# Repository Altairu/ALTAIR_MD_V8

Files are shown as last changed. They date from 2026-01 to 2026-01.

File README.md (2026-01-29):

# ALTAIR_MD_V8
**High-Power Isolated Motor Driver Board**

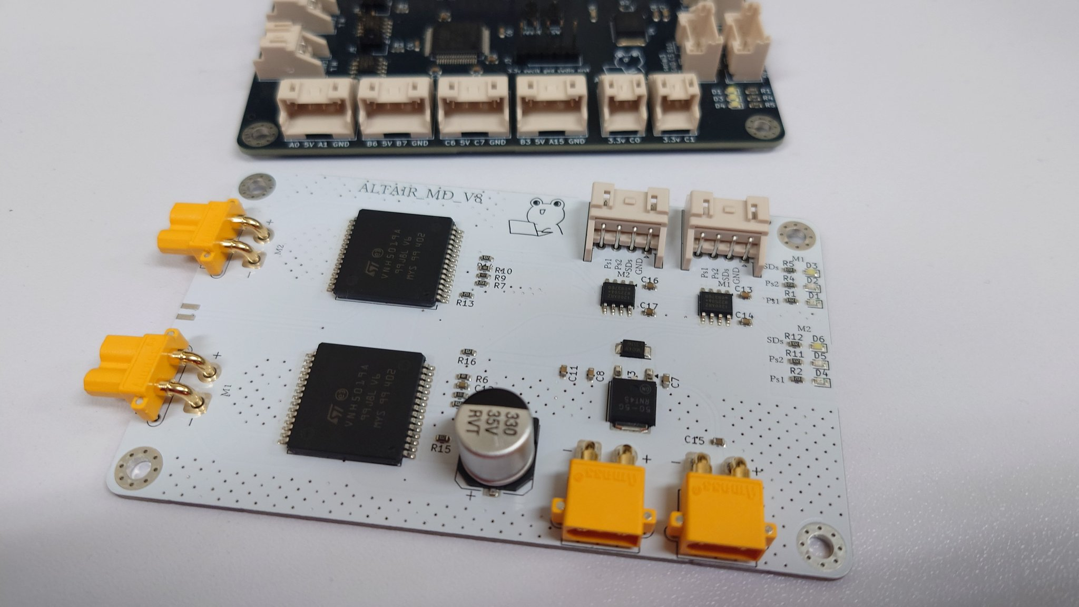
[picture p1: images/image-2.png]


<blockquote class="twitter-tweet"><p lang="ja" dir="ltr">NEWもたどら <a href="https://t.co/xIfIAs8RRS">pic.twitter.com/xIfIAs8RRS</a></p>&mdash; -Altair- (@Flying___eagle) <a href="https://twitter.com/Flying___eagle/status/2016806401205797079?ref_src=twsrc%5Etfw">January 29, 2026</a></blockquote> 

## 概要 (Overview)
**ALTAIR_MD_V8** は、STMicroelectronics製の車載用高出力フルブリッジドライバー **VNH5019A-E** を搭載したDCモータードライバーモジュールです。

制御信号ラインにデジタルアイソレータ (**ADuM121N**) を採用することで、モーター駆動系（24V系）とマイコン制御系（3.3V/5V系）のGNDを完全に分離（絶縁）しています。

## 特徴 (Features)
*   **高出力駆動**: 連続12A / 最大30A の大電流駆動が可能（VNH5019A-E仕様に基づく）。
*   **完全絶縁設計**: Analog Devices製 デジタルアイソレータ ADuM121N を採用し、ロジック側とパワー側のGNDを分離。
*   **広範囲なロジック電圧**: 1.8V ～ 5V のロジック入力に対応（マイコンを選ばない設計）。
*   **保護機能**:
    *   過電圧・低電圧シャットダウン
    *   過熱保護 (Thermal Shutdown)
    *   電流センシング機能 (Current Sense Output)

## 仕様 (Specifications)

| 項目 | 仕様 | 備考 |
| :--- | :--- | :--- |
| **メインドライバー** | STMicroelectronics VNH5019A-E | AEC-Q100準拠 (車載グレード) |
| **絶縁素子** | Analog Devices ADuM121N | 2ch デジタルアイソレータ (計2個使用) |
| **入力電源電圧** | DC 5.5V ～ 24V | パワー側電源 (VCC/VBAT) |
| **ロジック入力電圧** | DC 1.8V ～ 5.5V | マイコン側I/O電圧 |
| **最大出力電流** | 連続 12A / ピーク 30A | 放熱条件に依存 |
| **電流センシング** | アナログ電圧出力 | 1.5kΩ抵抗接続時 (約0.14V/A) |

## 回路図 (Schematic)

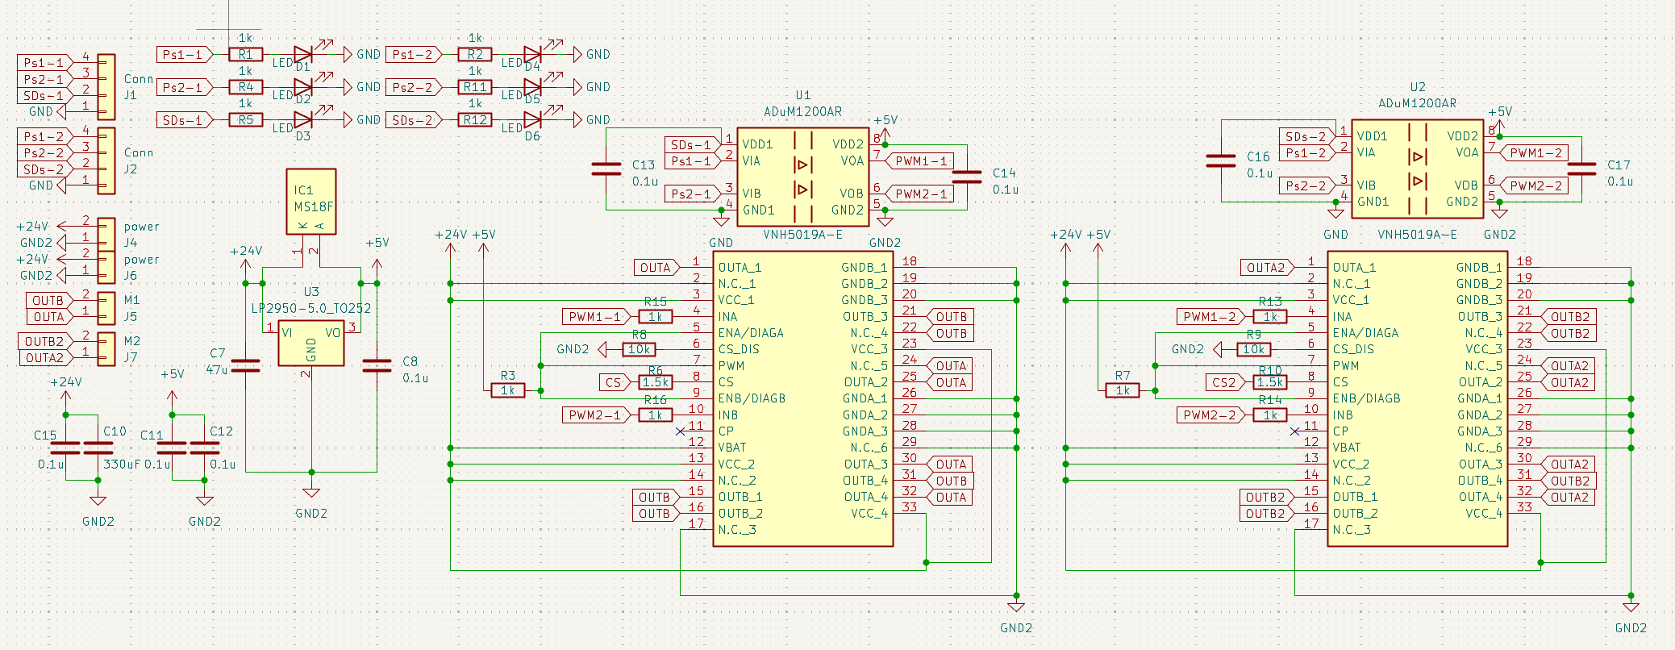
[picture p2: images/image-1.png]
Circuit Diagram


### 主な構成
*   **絶縁回路**: マイコンからの制御信号（PWM1, PWM2, ENABLE）は、ADuM121N を介して VNH5019A-E に伝送されます。
*   **電源生成**: 24V入力からオンボードの降圧レギュレータにより、絶縁二次側（ドライバー側）用の5V電源を生成しています。
*   **保護設定**:
    *   **CP (Charge Pump)**: オープン（未接続）
    *   **VBAT**: VCCと短絡（逆接保護MOSFETなし構成のため）
  
## PCB Layout

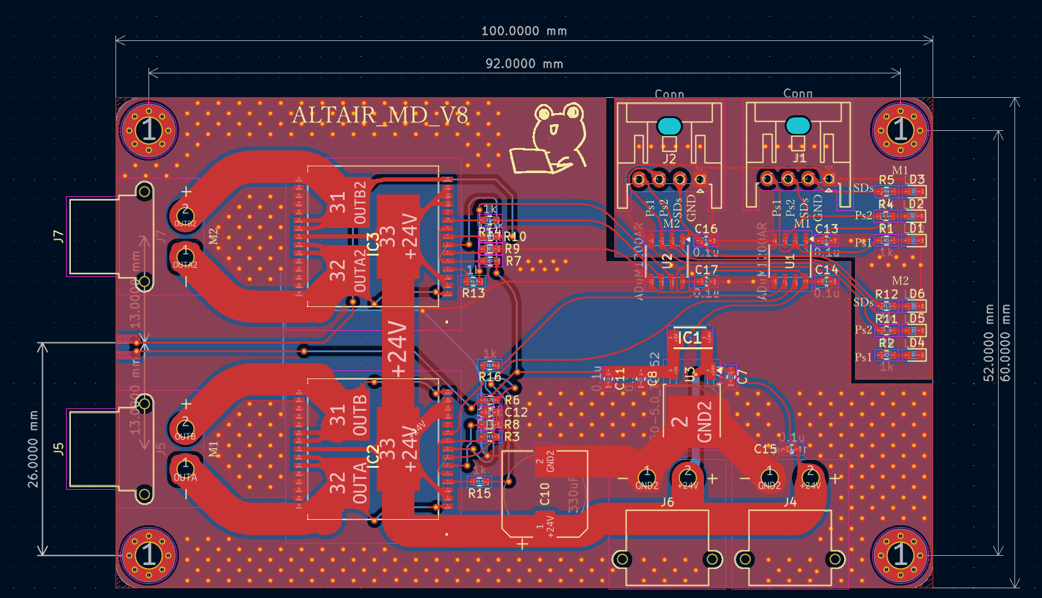
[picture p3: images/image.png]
PCB Layout


## インターフェース (Interface)

### 入力ピン (CN1 / マイコン側)
| ピン名 | 機能 | 説明 |
| :--- | :--- | :--- |
| **PWM1** | INA 入力 | モーター回転方向制御 A (正転/逆転) |
| **PWM2** | INB 入力 | モーター回転方向制御 B (正転/逆転) |
| **SD** | 動作許可 (PWM Pin) | **HIGH**: 動作許可, **LOW**: フリーラン停止 (全OFF) |
| **GND** | ロジックGND | マイコン側のGNDと接続 |

### 出力ピン (CN2 / モーター・電源側)
| ピン名 | 機能 | 説明 |
| :--- | :--- | :--- |
| **+24V** | 電源入力 (+) | モーター用メイン電源 (最大24V) |
| **GND_P** | パワーGND (-) | 電源およびモーターのグラウンド |
| **OUT A** | モーター出力 A | モーターの端子へ接続 |
| **OUT B** | モーター出力 B | モーターの端子へ接続 |
| **CS** | 電流センス出力 | 電流値に応じたアナログ電圧を出力 (ADCで読取可) |

## 制御ロジック (Truth Table)

VNH5019A-E の仕様に基づく真理値表です。
**SD (Shutdown/Enable)** ピンが HIGH の時のみモーターが駆動します。

| SD (Enable) | PWM1 (INA) | PWM2 (INB) | OUT A | OUT B | 動作モード |
| :---: | :---: | :---: | :---: | :---: | :--- |
| **L** | X | X | OPEN | OPEN | **フリーラン停止 (All OFF)** |
| **H** | **H** | **L** | **H** | **L** | **正転 (CW)** |
| **H** | **L** | **H** | **L** | **H** | **逆転 (CCW)** |
| **H** | **L** | **L** | **L** | **L** | **ブレーキ (GNDショート)** |
| **H** | **H** | **H** | **H** | **H** | **ブレーキ (VCCショート)** |

*   速度制御を行う場合は、回転方向に応じて PWM1 または PWM2 に PWM信号を入力し、もう片方を LOW にしてください。
*   惰性走行させたい場合は、SDピンを LOW にしてください。

## 電流センシング (Current Sense)
CSピンからは、モーター電流に比例した電流が出力されます。基板上の 1.5kΩ 抵抗により電圧に変換されています。

*   **計算式**: $V_{CS} \approx \frac{I_{OUT}}{K} \times 1.5k\Omega$
*   **K係数**: Typ. 7000 (VNH5019A-E datasheet)
*   **目安**: モーター電流 1A あたり 約 0.21V の出力

## 組み立て・使用上の注意
1.  **電源投入順序**: 
    ロジック回路(ADuM121N)は一次側・二次側両方に電源が必要です。+24V電源を投入することで二次側5Vが生成され、システムが動作可能になります。
2.  **放熱**:
    30A近い電流を流す場合、IC底面の放熱パッド（ヒートスラッグ）への熱設計が重要です。必要に応じてヒートシンクや強制空冷を行ってください。
3.  **配線**:
    電源ラインとモーター出力ラインは、大電流が流れるため可能な限り太く短い配線を使用してください。

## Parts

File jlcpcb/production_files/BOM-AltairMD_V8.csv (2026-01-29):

Comment | Designator | Footprint | LCSC | Quantity
0.1u | C11,C12,C13,C14,C15,C16,C17,C8 | C_0603_1608Metric | C3011705 | 8
1.5k | R10,R6 | R_0603_1608Metric | C22843 | 2
10k | R8,R9 | R_0603_1608Metric | C15401 | 2
1k | R1,R11,R12,R13,R14,R15,R16,R2,R3,R4,R5,R7 | R_0603_1608Metric | C14676 | 12
330uF | C10 | CP_Elec_10x10 | C19606 | 1
47u | C7 | C_0603_1608Metric | C140782 | 1
ADuM1200AR | U1,U2 | SOIC-8_3.9x4.9mm_P1.27mm | C660246 | 2
LED | D1,D4 | LED_0603_1608Metric | C2286 | 2
LED | D2,D5 | LED_0603_1608Metric | C2288 | 2
LED | D3,D6 | LED_0603_1608Metric | C2290 | 2
LP2950-5.0_TO252 | U3 | TO-252-2 | C179571 | 1
MS18F | IC1 | SODFL4725X110N | C60396 | 1
VNH5019A-E | IC2,IC3 | VNH5019AE | C2653552 | 2

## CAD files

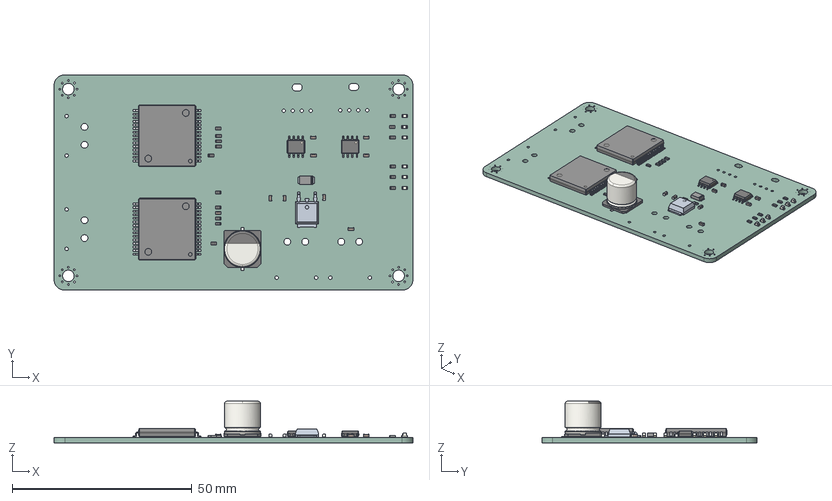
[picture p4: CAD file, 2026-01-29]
AltairMD_V8.step
100.0 x 60.0 x 11.6 mm
R_0603_1608Metric x 16
CP_Elec_10x10
LED_0603_1608Metric x 6
C_0603_1608Metric x 9
AltairMD_V8 1.7.1
SOIC-8_3.9x4.9mm_P1.27mm x 2
PinKIdent
PinK
PinA
VNH5019A-E x 2
AltairMD_V8_PCB

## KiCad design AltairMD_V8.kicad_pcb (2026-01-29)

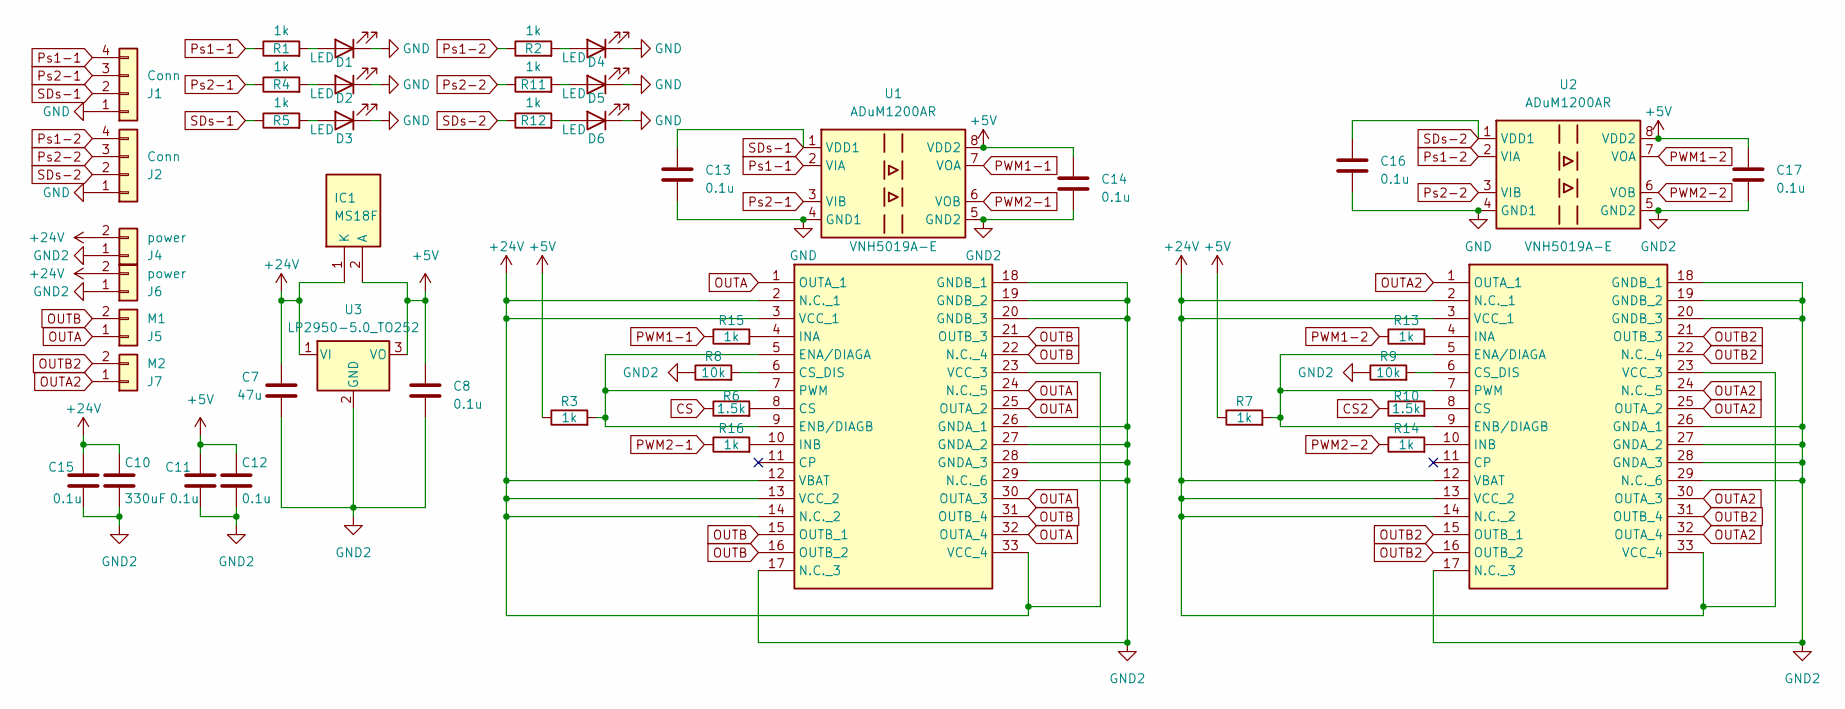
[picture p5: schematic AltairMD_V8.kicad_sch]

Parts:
C7: 47u; C_0603_1608Metric
C8, C11, C12, C13, C14, C15, C16, C17: 0.1u; C_0603_1608Metric
C10: 330uF; CP_Elec_10x10
D1, D2, D3, D4, D5, D6: LED; LED_0603_1608Metric
IC1: MS18F; SODFL4725X110N; Manufacturer_Part_Number MS18F
IC2, IC3: VNH5019A-E; VNH5019AE; Manufacturer_Part_Number VNH5019A-E; Mouser Part Number 511-VNH5019A-E
J1, J2: Conn; JST_XA_S04B-XASK-1_1x04_P2.50mm_Horizontal
J4, J6: power; AMASS_XT30PW-M_1x02_P2.50mm_Horizontal
J5: M1; AMASS_XT30PW-F_1x02_P2.50mm_Horizontal
J7: M2; AMASS_XT30PW-F_1x02_P2.50mm_Horizontal
R1, R2, R3, R4, R5, R7, R11, R12, R13, R14, R15, R16: 1k; R_0603_1608Metric
R6, R10: 1.5k; R_0603_1608Metric
R8, R9: 10k; R_0603_1608Metric
U1, U2: ADuM1200AR; SOIC-8_3.9x4.9mm_P1.27mm
U3: LP2950-5.0_TO252; TO-252-2

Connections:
+5V: C8.1, C11.1, C12.1, C14.1, C17.1, IC1.2 (A), R3.1, R7.1, U1.8 (VDD2), U2.8 (VDD2), U3.3 (VO)
+24V: C7.1, C10.1, C15.1, IC1.1 (K), IC2.2 (N.C._1), IC2.3 (VCC_1), IC2.12 (VBAT), IC2.13 (VCC_2), IC2.14 (N.C._2), IC2.23 (VCC_3), IC2.33 (VCC_4), IC3.2 (N.C._1), IC3.3 (VCC_1), IC3.12 (VBAT), IC3.13 (VCC_2), IC3.14 (N.C._2), IC3.23 (VCC_3), IC3.33 (VCC_4), J4.2, J6.2, U3.1 (VI)
CS: R6.1
CS2: R10.1
GND: C13.2, C16.2, D1.1 (K), D2.1 (K), D3.1 (K), D4.1 (K), D5.1 (K), D6.1 (K), J1.1, J2.1, U1.4 (GND1), U2.4 (GND1)
GND2: C7.2, C8.2, C10.2, C11.2, C12.2, C14.2, C15.2, C17.2, IC2.17 (N.C._3), IC2.18 (GNDB_1), IC2.19 (GNDB_2), IC2.20 (GNDB_3), IC2.26 (GNDA_1), IC2.27 (GNDA_2), IC2.28 (GNDA_3), IC2.29 (N.C._6), IC3.17 (N.C._3), IC3.18 (GNDB_1), IC3.19 (GNDB_2), IC3.20 (GNDB_3), IC3.26 (GNDA_1), IC3.27 (GNDA_2), IC3.28 (GNDA_3), IC3.29 (N.C._6), J4.1, J6.1, R8.1, R9.1, U1.5 (GND2), U2.5 (GND2), U3.2 (GND)
unnamed: D1.2 (A), R1.2
unnamed: D2.2 (A), R4.2
unnamed: D3.2 (A), R5.2
unnamed: D4.2 (A), R2.2
unnamed: D5.2 (A), R11.2
unnamed: D6.2 (A), R12.2
unnamed: IC2.8 (CS), R6.2
unnamed: IC2.6 (CS_DIS), R8.2
unnamed: IC2.5 (ENA/DIAGA), IC2.7 (PWM), IC2.9 (ENB/DIAGB), R3.2
unnamed: IC2.4 (INA), R15.2
unnamed: IC2.10 (INB), R16.2
unnamed: IC3.8 (CS), R10.2
unnamed: IC3.6 (CS_DIS), R9.2
unnamed: IC3.5 (ENA/DIAGA), IC3.7 (PWM), IC3.9 (ENB/DIAGB), R7.2
unnamed: IC3.4 (INA), R13.2
unnamed: IC3.10 (INB), R14.2
OUTA: IC2.1 (OUTA_1), IC2.24 (N.C._5), IC2.25 (OUTA_2), IC2.30 (OUTA_3), IC2.32 (OUTA_4), J5.1
OUTA2: IC3.1 (OUTA_1), IC3.24 (N.C._5), IC3.25 (OUTA_2), IC3.30 (OUTA_3), IC3.32 (OUTA_4), J7.1
OUTB: IC2.15 (OUTB_1), IC2.16 (OUTB_2), IC2.21 (OUTB_3), IC2.22 (N.C._4), IC2.31 (OUTB_4), J5.2
OUTB2: IC3.15 (OUTB_1), IC3.16 (OUTB_2), IC3.21 (OUTB_3), IC3.22 (N.C._4), IC3.31 (OUTB_4), J7.2
PWM1-1: R15.1, U1.7 (VOA)
PWM1-2: R13.1, U2.7 (VOA)
PWM2-1: R16.1, U1.6 (VOB)
PWM2-2: R14.1, U2.6 (VOB)
Ps1-1: J1.4, R1.1, U1.2 (VIA)
Ps1-2: J2.4, R2.1, U2.2 (VIA)
Ps2-1: J1.3, R4.1, U1.3 (VIB)
Ps2-2: J2.3, R11.1, U2.3 (VIB)
SDs-1: C13.1, J1.2, R5.1, U1.1 (VDD1)
SDs-2: C16.1, J2.2, R12.1, U2.1 (VDD1)

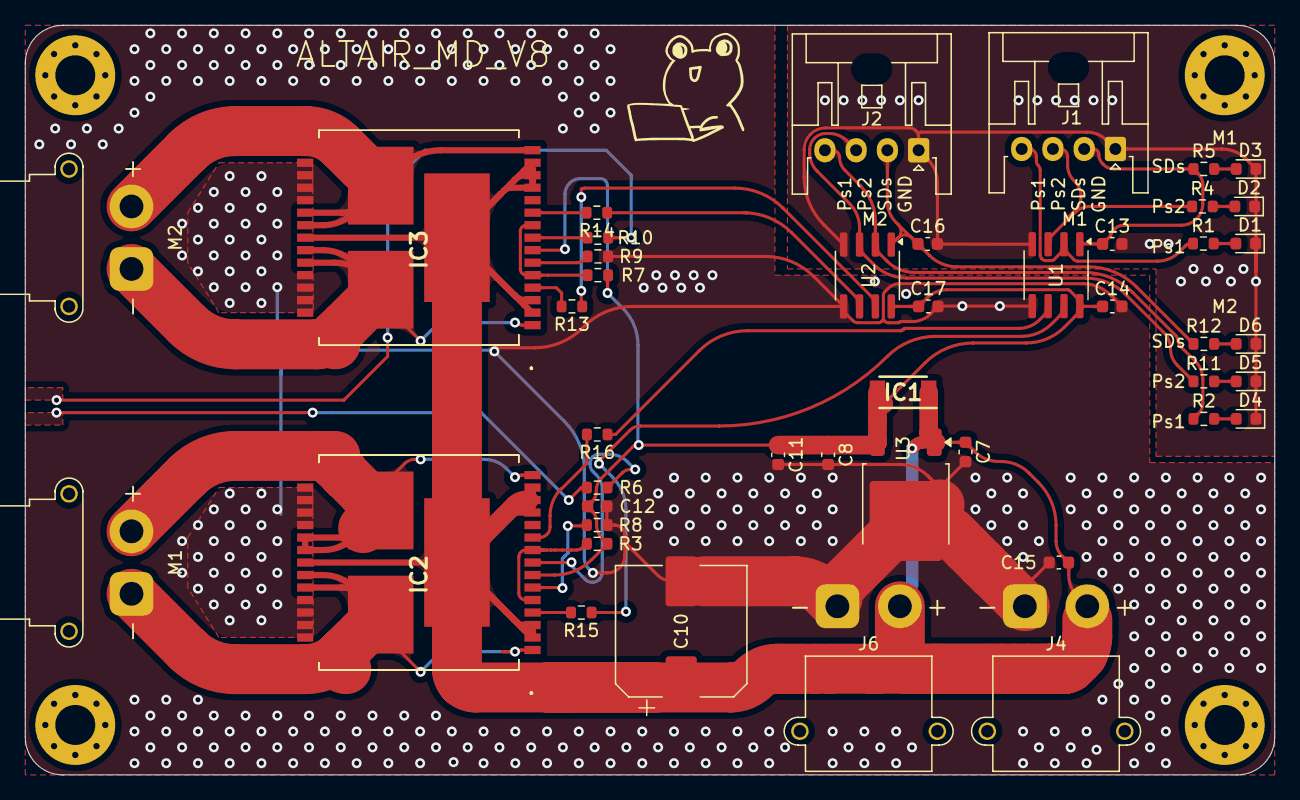
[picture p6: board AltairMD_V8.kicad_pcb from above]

Board: 2 copper layers, 100.0 x 60.0 mm, 48 parts (0 on the bottom side), 34 nets.

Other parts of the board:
H1, H2, H3, H4: MountingHole; MountingHole_3.2mm_M3_Pad_Via
